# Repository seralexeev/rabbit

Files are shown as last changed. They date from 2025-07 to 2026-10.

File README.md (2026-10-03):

# Rabbit

A small home-built Ackermann rover that maps a flat on its own, drives to things you name ("drive to the fridge") and explains what it did. Everything is in this repo: the robot code, the web HUD, the telemetry store with its AI agent, the hardware design for the next version, and the build log.

Build log (Russian and English): **[rabbit0.dev](https://rabbit0.dev)** · Live HUD: https://live.rabbit0.dev (by personal link)

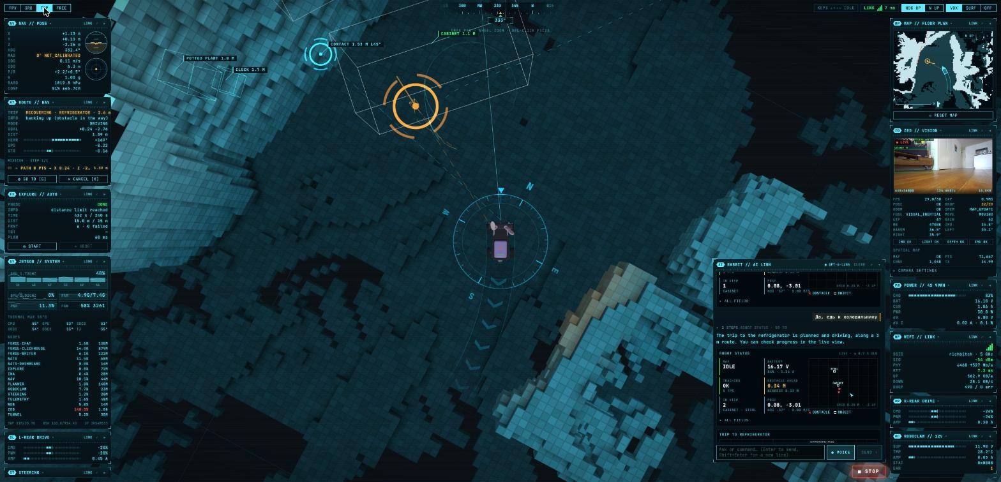
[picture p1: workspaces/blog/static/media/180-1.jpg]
The HUD on a trip to the fridge: voxel map, detected objects, planned path and the AI chat


## What it does

- **Maps and localizes with one stereo camera.** A ZED 2i provides depth, visual-inertial odometry and object detection. nvblox builds a voxel map and a clearance grid on the GPU, and the robot relocalizes in its saved map after a restart. Relocalizing after being carried to another room is the open problem; RTAB-Map is replacing ZED GEN_3 for it.
- **Plans and drives like a car.** A Hybrid A* planner knows the robot's asymmetric turning radius and plans forward and reverse manoeuvres. A path tracker follows the plan on the rear axle, and a collision guard checks the swept footprint against the live obstacle scan.
- **Explores by itself.** It picks views by information gain and finishes a room before leaving it.
- **Takes orders in plain language.** The HUD chat, by text or voice, talks to Forge, an agent that answers from the recorded telemetry ("why did it stop at 03:12?") and can send trips after the operator approves them.
- **Records everything.** Every pose, command, decision with its reason, log line and power sample goes into Parquet files, queried with chDB (embedded ClickHouse).
- **Runs headless.** The HUD is only a viewer: the robot doesn't care whether anyone is watching.

| | |
|---|---|
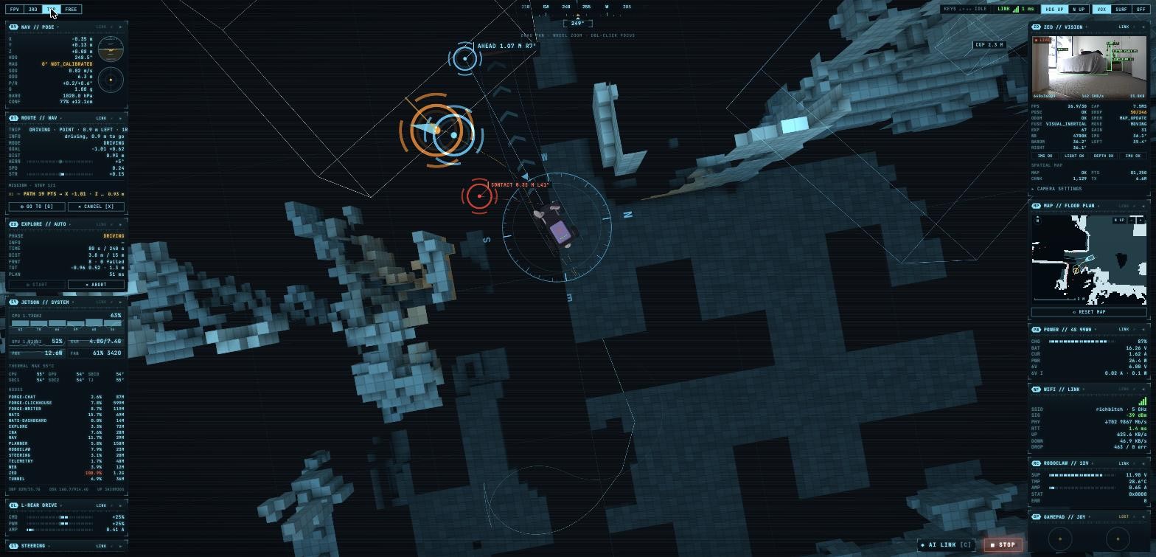
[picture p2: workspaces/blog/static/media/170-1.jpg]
Top view: path, contact warnings and the floor plan
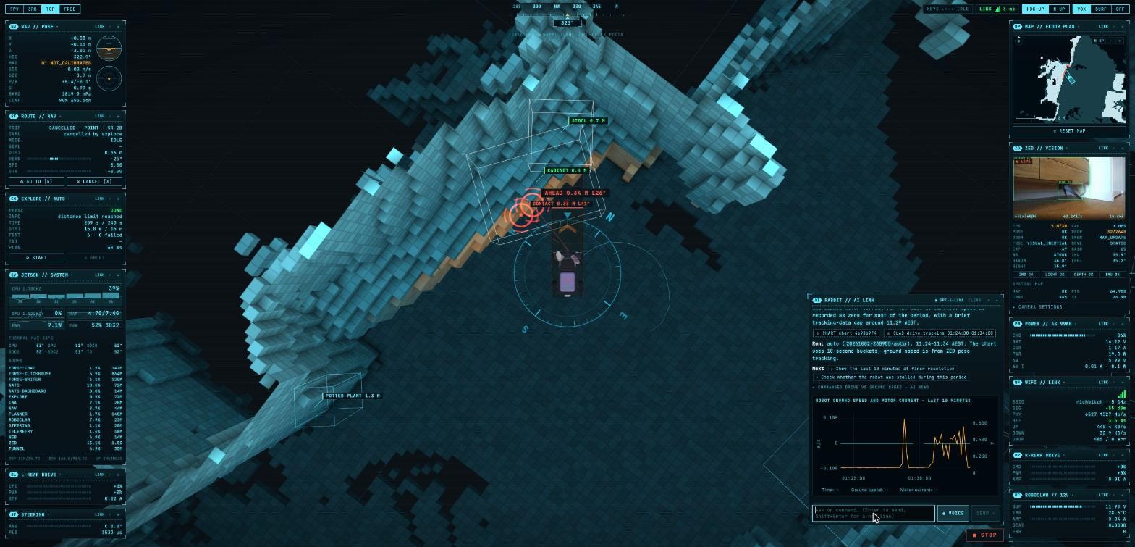
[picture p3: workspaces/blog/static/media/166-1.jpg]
The AI link answering from telemetry with a chart
|  |  |

## Hardware

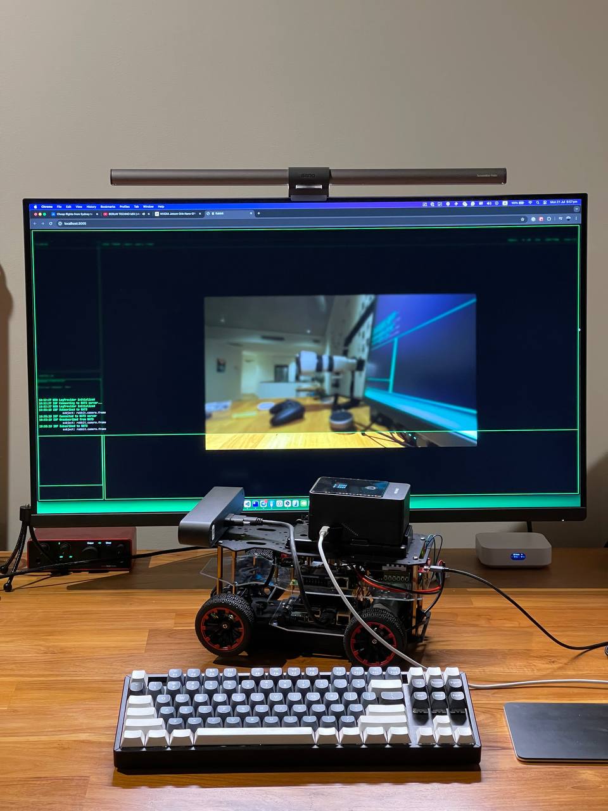
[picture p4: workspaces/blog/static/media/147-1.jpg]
Rabbit on the desk with the early HUD


| Part | What |
|---|---|
| Chassis | "Red Ackerman Racing Car" metal kit; front steering, rear drive. Wheelbase 0.17 m, 75 mm wheels, ~3.5 kg |
| Brain | NVIDIA Jetson Orin Nano Super 8 GB (JetPack 6, MAXN_SUPER, headless) |
| Camera | Stereolabs ZED 2i (depth, VIO, IMU, barometer, magnetometer) |
| Drive | 2 × Pololu 37D 70:1 12 V gearmotors on a RoboClaw 2x30A; electronic differential in software |
| Steering | AGFRC A50BHL brushless servo via a PCA9685 |
| Power | NEEWER PS099E V-mount battery (99 Wh, 4S Li-ion) and Pololu step-down regulators; INA4235 4-channel power monitor |
| Network | Wi-Fi only; NATS over websockets for the HUD; a Cloudflare tunnel for public access |

## Software

Python nodes talk over [NATS](https://nats.io) instead of ROS, one Docker container per node on the Jetson.

```
 ZED 2i ─► rabbit-zed ──pose/odom, obstacle scan, objects, map──► rabbit-nav ──drive──► rabbit-roboclaw ─► motors
              │                                              ▲        │                rabbit-steering ─► servo
              └─► rabbit-loc (RTAB-Map, map←odom)            │        └─ safety trips, recovery
                                   rabbit-planner (Hybrid A*) ┤
                                   rabbit-explore (frontiers) ┘
 rabbit-ina, rabbit-telemetry ─► power, Jetson, Docker, Wi-Fi
 all subjects ─► Forge (Parquet + chDB) ─► slabs, MCP, HUD chat agent
 HUD (React, three.js, uPlot) ◄── NATS websocket, served by rabbit-web (nginx)
```

| Path | What |
|---|---|
| [`workspaces/rabbit`](workspaces/rabbit) | robot nodes (`src/node/`), libraries (`src/lib/`), native extensions (nvblox, RTAB-Map), tests, the simulator |
| [`workspaces/web`](workspaces/web) | the HUD |
| [`workspaces/forge`](workspaces/forge) | Forge: telemetry writer, store, slabs, metric graph, MCP server and chat agent ([README](workspaces/forge/README.md)) |
| [`workspaces/blog`](workspaces/blog) | the build log at rabbit0.dev |
| [`workspaces/bench`](workspaces/bench) | localization benchmark and recording tools |
| [`workspaces/compose.yaml`](workspaces/compose.yaml), [`workspaces/nats`](workspaces/nats), [`workspaces/jetson`](workspaces/jetson) | services, NATS config, Jetson boot tuning |
| [`pcb/rabbit-body`](pcb/rabbit-body), [`cad/brackets`](cad/brackets), [`model`](model) | Rabbit 2.0 body PCB, 3D-printed mounts, chassis model |
| [`docs`](docs) | engineering log, reports, roadmap, open issues, lessons |
| [`scripts`](scripts) | deploy, bring-up, simulator, access links, blog |

## Rabbit 2.0

The next version splits the robot into a **brain** and a **body**:
- the Jetson keeps only GPU work: perception, localization and planning;
- a Raspberry Pi 4 becomes the body. It runs the motors, the steering, the power, an independent safety loop, a 360° lidar, ToF sensors and bumpers, a rear camera, Forge and the HUD.

The body electronics move from an acrylic deck full of modules onto one PCB shaped like the chassis deck. The board is generated from Python with KiCad and Freerouting.

| | |
|---|---|
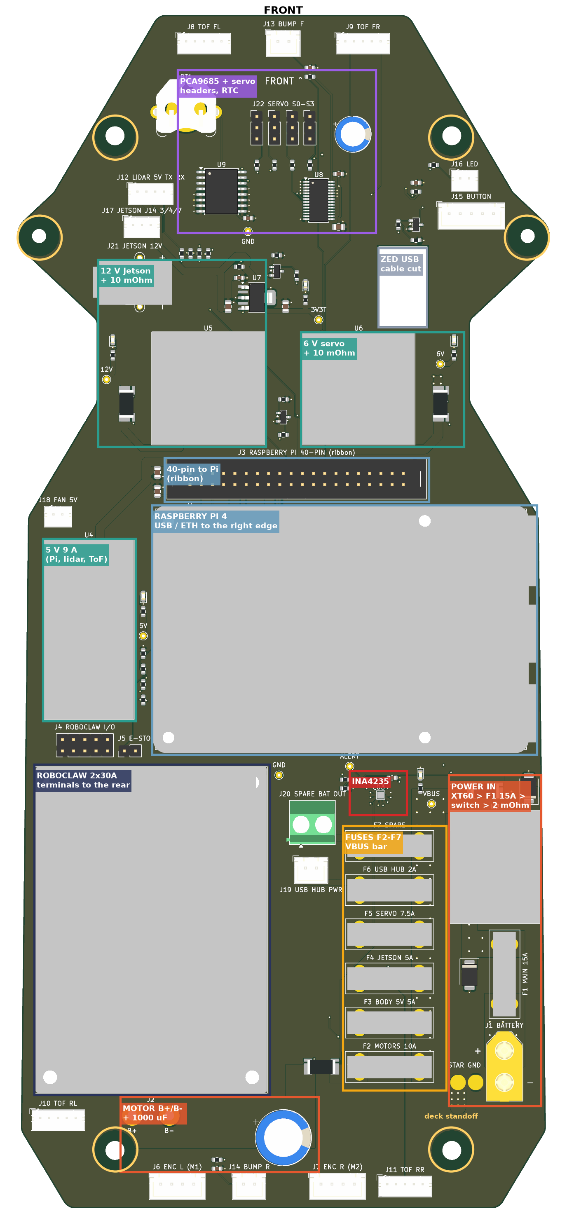
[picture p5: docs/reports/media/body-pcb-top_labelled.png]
Body PCB, top view with the main blocks labelled
|  | Wiring overview: every device and link |
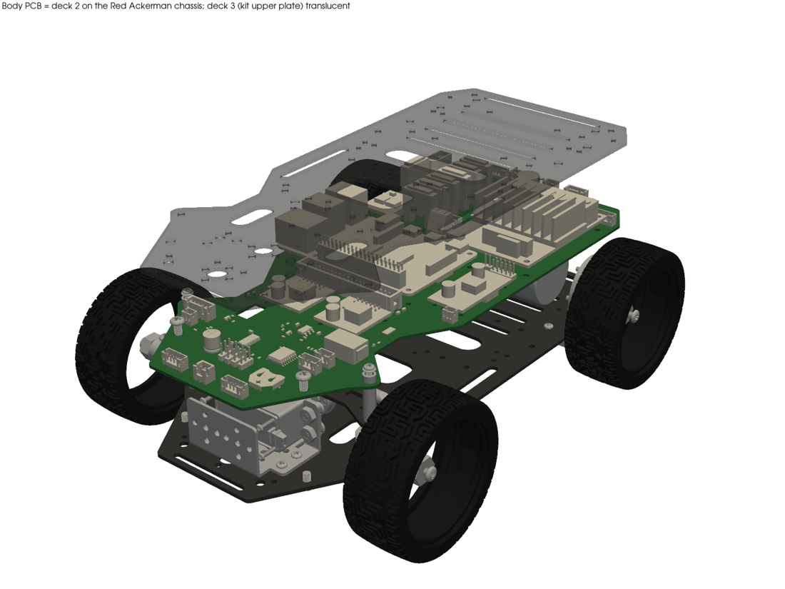
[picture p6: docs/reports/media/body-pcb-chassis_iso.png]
The PCB as the middle deck on the chassis
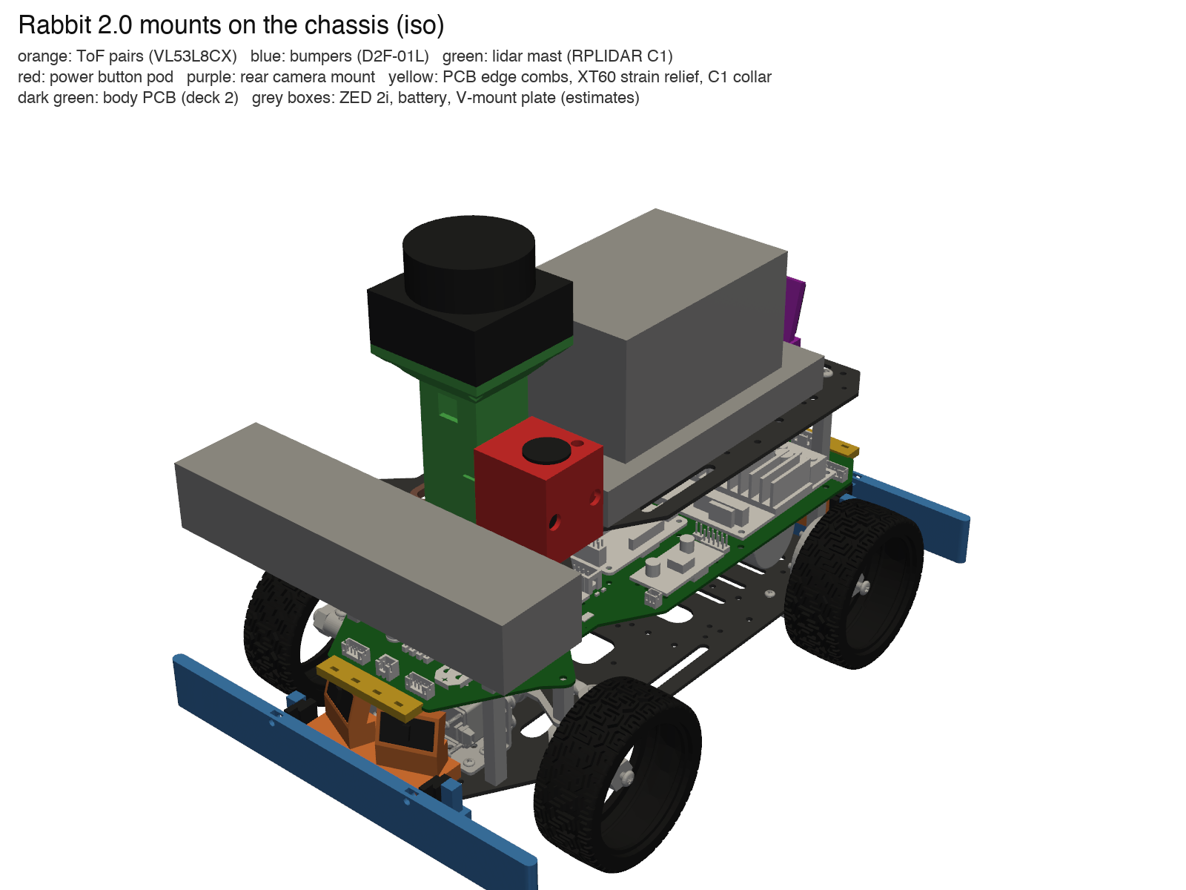
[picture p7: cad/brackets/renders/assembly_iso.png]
3D-printed mounts: ToF pairs, bumpers, lidar mast
|  |  |

Design: [architecture](docs/reports/2026-10-03-architecture-2.0.md) · [wiring](docs/reports/2026-10-03-architecture-2.0-wiring.md) · [BOM](docs/reports/2026-10-03-architecture-2.0-bom.md) · [body PCB](docs/reports/2026-10-03-body-pcb.md) · [mounts](docs/reports/2026-10-03-mounts.md) · [power](docs/reports/media/power-2.0.svg)

## Working on it

The project is developed mostly by coding agents. [`AGENTS.md`](AGENTS.md) holds the rules, and the skills in [`.claude/skills`](.claude/skills) hold the procedures:
- `rabbit-robot`: operating and deploying the robot;
- `rabbit-dev`: robot code and the HUD;
- `forge-dev`: Forge;
- `rabbit-blog`: the blog.

```sh
# robot tests
cd workspaces/rabbit && uv run --no-project --python 3.10 --with pytest --with numpy --with pydantic --with numba --with nats-py python -m pytest tests -q

# full-stack simulator on the Mac: local NATS + rabbit-sim + the real nav, planner and explore
scripts/sim.sh

# HUD dev server at https://localhost:3005
cd workspaces/web && node ../../.yarn/releases/yarn-4.9.3.cjs dev

# deploy named services to the robot
scripts/deploy.sh rabbit-nav rabbit-web

# after the robot was off: checks, deploy, tests, step by step
uv run scripts/bringup.py check
```

## Work log and blog

Every piece of significant work leaves two traces, written as part of the work:

1. **Engineering log** in [`docs/`](docs/README.md), in English and factual:
   - `docs/log/YYYY-MM-DD-<topic>.md`: what was tried and dropped, numbers, root causes;
   - [`docs/roadmap.md`](docs/roadmap.md): what's next;
   - [`docs/open-issues.md`](docs/open-issues.md): open questions and unresolved problems;
   - [`docs/lessons.md`](docs/lessons.md): rules learned the hard way.
2. **Blog post** at [rabbit0.dev](https://rabbit0.dev), in the author's voice:
   - source in [`workspaces/blog`](workspaces/blog): `README.ru.md` holds the Russian posts, `README.md` the English ones, `static/media/` the media;
   - `scripts/blog.sh build` renders the pages;
   - a push to `main` that touches `workspaces/blog` deploys it to GitHub Pages ([`.github/workflows/blog.yml`](.github/workflows/blog.yml)).

## Access links

The public HUD at https://live.rabbit0.dev opens only through a personal link; the LAN address (https://jetson.rabbit) stays open. Ask the agent "give me a link" (optionally "for Alice") or "remove Alice's link", or run it yourself:

```sh
scripts/links.sh              # list: name, date, link
scripts/links.sh add alice    # create a link, prints https://live.rabbit0.dev/k/<token>
scripts/links.sh rm alice     # revoke it: the open HUD is cut off within ~5 s
```

The registry lives only on the robot, in `/root/rabbit/workspaces/links/links.map`. Details are in the `rabbit-robot` skill.

Old hardware and setup scratch notes: [`docs/notes.md`](docs/notes.md).

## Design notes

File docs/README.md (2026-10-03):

# Engineering log

Notes for people and agents who pick up this project later: what the system looks like now, how it got there, what was tried and dropped, the measurements behind decisions and the incidents with their root causes. The how-to material (deploying, operating, developing) lives in `AGENTS.md`, `.claude/skills/*` and `workspaces/forge/README.md`; this folder is the history and the reasoning.

Open questions, unresolved problems and on-robot checks: [open-issues.md](open-issues.md). What to do next: [roadmap.md](roadmap.md).

Conventions: dates in file names and timestamps are UTC unless marked otherwise; the robot and its owner are in Sydney (AEST, UTC+10, AEDT from 4 October 2026). Commit hashes refer to this repository. Everything after commit `b36435d` (2026-10-02 00:49 UTC) was uncommitted when these notes were written (2026-10-03); those entries name files instead of commits. Reports referred to as `~/projects/rabbit/data/offline/...` are kept outside the repo because they contain maps and data of the flat.

What's next: [roadmap.md](roadmap.md).

## Index

| Entry | Topic |
|---|---|
| [2025-05-18 hardware and stack history](log/2025-05-18-hardware-and-stack-history.md) | hardware, the move from Raspberry Pi to Jetson, ROS 2 → NATS, state after five months off |
| [2026-10-01 revival and telemetry](log/2026-10-01-revival-and-telemetry.md) | node rewrite, RoboClaw/INA/IMU telemetry, `jetson_clocks`, TLS and Chrome |
| [2026-10-01 ZED spatial mapping](log/2026-10-01-zed-spatial-mapping.md) | SDK 5.5, room map, memory, quality tuning, mesh filter, chunk format (superseded) |
| [2026-10-01 driving, nav and safety](log/2026-10-01-driving-nav-and-safety.md) | nav node, missions, swept-arc guard, wall crash, calibration, rear-axle tracking |
| [2026-10-01 exploration and Hybrid A*](log/2026-10-01-exploration-and-hybrid-astar.md) | frontier exploration and the planner kernels |
| [2026-10-01 Forge](log/2026-10-01-forge.md) | ClickHouse writer, slabs, MCP, chat agent, anomalies, moving onto the robot |
| [2026-10-01 HUD](log/2026-10-01-hud.md) | 3D HUD, chat panel, minimap, voxel map, objects |
| [2026-10-01 lag and Wi-Fi](log/2026-10-01-lag-and-wifi.md) | the lag hunt, Wi-Fi drops, TX power |
| [2026-10-01 public access](log/2026-10-01-public-access.md) | Cloudflare tunnel, access links, HTTP/2 |
| [2026-10-01 map resets](log/2026-10-01-map-resets.md) | every map reset or loss and its cause |
| [2026-10-01 deploy and agent workflow](log/2026-10-01-deploy-and-agent-workflow.md) | deploy script, parallel agent sessions |
| [2026-10-02 Jetson performance](log/2026-10-02-jetson-performance.md) | clocks, IRQs, headless, the clock-floor incident, OC3, JetPack assessment |
| [2026-10-02 ZED optimisation](log/2026-10-02-zed-optimisation.md) | CPU, GIL, frame rates, depth, GEN_3 keyframe leak, map modes |
| [2026-10-02 nvblox](log/2026-10-02-nvblox.md) | nvblox extension, clearance grid, reflections, debris |
| [2026-10-02 floor estimation](log/2026-10-02-floor-estimation.md) | floor origin, per-frame floor plane, robot on a table |
| [2026-10-02 route planner](log/2026-10-02-route-planner.md) | `rabbit-planner`: trips to points, places and objects; replay |
| [2026-10-02 object detector](log/2026-10-02-object-detector.md) | YOLOE in the ZED SDK, filtering, objects in Forge |
| [2026-10-02 voice agent](log/2026-10-02-voice-agent.md) | Realtime voice, spoken approvals, robot prompt |
| [2026-10-02 relocalization](log/2026-10-02-relocalization.md) | millimetre poses, false relocalization, give-up rules |
| [2026-10-02 odom/map split](log/2026-10-02-odom-map-split.md) | nav on continuous odometry |
| [2026-10-02 operator heartbeat removal](log/2026-10-02-operator-heartbeat-removal.md) | the HUD is a viewer |
| [2026-10-02 NATS/Docker latency](log/2026-10-02-nats-docker-latency.md) | latency audit and NATS settings |
| [2026-10-02 SLAM survey and benchmark](log/2026-10-02-slam-survey-and-benchmark.md) | cuVSLAM / RTAB-Map vs ZED GEN_3 (in progress) |
| [2026-10-03 motor slew limit](log/2026-10-03-motor-slew-limit.md) | smoothing bursty joystick commands |
| [2026-10-03 Forge on Parquet and chDB](log/2026-10-03-forge-parquet-chdb.md) | ClickHouse server replaced by Parquet files and embedded chDB: design, parity, memory |
| [2026-10-03 Jetson diet and Python 3.12](log/2026-10-03-jetson-diet.md) | trimming host services, journald, logrotate, image pruning; Python 3.12 patch |
| [2026-10-03 field session](log/2026-10-03-field-session.md) | boot after a move, recordings, nav safety trips, far-floor phantom obstacles |
| [2026-10-03 power rails](log/2026-10-03-power-rails.md) | battery, motor, servo and Jetson currents from telemetry; the motor buck at its limit, the battery shunt near its range |
| [2026-10-03 Rabbit 2.0 made buildable](log/2026-10-03-architecture-2.0-detail.md) | Pi 4 body: BOM, pinout and buses, fail-safe E-stop, NATS hub + leaf, INA4235 channels and shunts, wiring diagrams |
| [2026-10-03 nav replay](log/2026-10-03-nav-replay.md) | offline replay of the day's trips: recovery along the trail, turnaround loops, `stuck`, IMU thresholds |
| [2026-10-03 full-stack simulator](log/2026-10-03-full-stack-sim.md) | `rabbit-sim` + local NATS + the real nav/planner/explore on the Mac, end-to-end tests |
| [2026-10-03 observability](log/2026-10-03-observability.md) | structured events with reasons and ids, node metrics, start snapshots, `events` / `node_starts` / `node_metrics` / `nats_server` in Forge |
| [2026-10-03 phase 0 tools](log/2026-10-03-phase-0-tools.md) | INA per-channel shunts and `clipped`, duty cap 12 V / V_supply, RoboClaw config tool (3 A, NVM), encoder check |
| [2026-10-03 printed mounts](log/2026-10-03-printed-mounts.md) | Rabbit 2.0 brackets in `cad/brackets/`: ToF pairs, compliant bumpers with D2F switches, lidar mast (scan plane 230 mm), button pod, rear camera mount, body-PCB clips and grommets; fit checks against the 3-deck stack with the PCB STEP; the USB hub has no place yet |
| [2026-10-03 body PCB](log/2026-10-03-body-pcb.md) | deck-2 board for Rabbit 2.0 generated by code (KiCad 10 + Freerouting): Pi, RoboClaw, regulators, fuses, INA4235, PCA9685; stack heights, current paths, DRC clean, JLCPCB outputs |
| [2026-10-03 body PCB review](log/2026-10-03-body-pcb-review.md) | independent pre-order review of rev A: pin-by-pin checks pass; fixed input TVS, ToF and 5 V rail resistance, motor star, stale net classes, ZED cut-out, INA4235 paste, BOM; PCA9685/INA4235 stock blocks JLC assembly; factory-assembly options and rev B lessons |
| [2026-10-03 BLDC drive study](log/2026-10-03-bldc-drive.md) | why the 37D 70:1 is slow and loud, torque/speed needs per wheel, the motor mount measured in the chassis model, BLDC/brushed/gimbal options, DRV8316 + STM32G4 on the body PCB, regen with a V-mount BMS; report `reports/2026-10-03-bldc-drive.md` |
| [2026-10-03 BLDC drive mount](log/2026-10-03-bldc-drive-mount.md) | final BLDC choice (maxon ECX FLAT 22 L + GPX 22 LN 16:1 + ENX 22 MILE; Faulhaber 3216 fallback), new 6061 bracket with its own wheel bearings and an Oldham coupling inside a hollow stub axle, printed test-fit variant, fit check in the widened chassis, wiring to the rev B connectors; `cad/drive/` |
| [2026-10-03 body software](log/2026-10-03-body-software.md) | Rabbit 2.0 body written offline: `rabbit-lidar` (RPLIDAR C1 protocol, timestamps, de-skew), `rabbit-tof` (VL53L8CX ×4, floor rejection), `rabbit-safety` (50 Hz arbiter, caps by clearance and input freshness, E-stop line self-test), `rabbit-power` (shutdown state machine), fake GPIO/serial/ToF backend, lidar/ToF/bumpers in the simulator, nav and planner on the lidar scan, Forge tables, Pi compose and deploy; Raspberry Pi kernels keep GPIO outputs after a crash |
| [2026-10-03 body PCB rev B](log/2026-10-03-body-pcb-rev-b.md) | deck-2 board rev B: STM32G474 + 2× DRV8316 BLDC drive with hardware E-stop and brake chopper, LM74800 soft-latch switch, LM61495 bucks, TPS16630 Jetson eFuse, 4× INA226, SMD fuses, GND_MOT island; everything JLC-stocked and JLC-assembled; Freerouting fed filled pours |

[lessons.md](lessons.md) collects the hard-won rules in one list.

## Current state of the system (2026-10-03)

### Hardware

Jetson Orin Nano Super 8 GB (MAXN_SUPER, clocks pinned, headless), ZED 2i on USB, RoboClaw 2x30A on the UART, PCA9685 steering servo, INA4235 power monitor, 99 Wh 4S Li-ion pack, Wi-Fi only. Wheel encoders do not count; speed comes from the camera pose. Details in the hardware entry.

### Services (`workspaces/compose.yaml`)

| Service | Role |
|---|---|
| `nats`, `nats-init`, `nats-dashboard` | message bus; KV bucket `rabbit`, JetStream `LOGS` (7 days) |
| `rabbit-zed` | the only camera process: GEN_3 tracking and relocalization, depth (NEURAL_LIGHT, every 2nd frame), nvblox mapping (C++/CUDA extension), floor estimation, obstacle scan, YOLOE object detection, preview, SVO recording, health |
| `rabbit-nav` | missions (`move`, `turn`, `goto`, `path`), path tracking on the rear axle in the odometry frame (curvature feedforward + feedback), swept-footprint collision guard with blind-zone memory, stall and bump trips |
| `rabbit-planner` | Hybrid A* trips to points, saved places and objects; replanning and recovery |
| `rabbit-explore` | exploration by expected information gain per metre, through planner trips |
| `rabbit-roboclaw`, `rabbit-steering` | motors (electronic differential, slew limiting, kill switch) and the servo |
| `rabbit-ina`, `rabbit-telemetry` | power at 50 Hz; Jetson, containers and Wi-Fi at 1 Hz |
| `forge` | NATS → Parquet writer, compaction, chDB queries, chat/voice agent API, in one process |
| `rabbit-web` | nginx: the built HUD, `/api` → chat, `/nats` → NATS websocket, access-link gate |
| `tunnel` | Cloudflare tunnel (HTTP/2) to https://live.rabbit0.dev |

All `rabbit-*` nodes share one image with the code bind-mounted; a code change needs a container recreate, not a rebuild.

### Main NATS contracts

- Sensors: `rabbit.zed.pose` (map pose plus an `odom` sub-object; floor at y = 0, camera at y ≈ 0.137), `rabbit.zed.imu`, `rabbit.zed.obstacle` (48-bin scan over ±60°, obstacles 4–45 cm above a per-frame floor plane), `rabbit.zed.objects`, `rabbit.health.zed` (fps, `spatial_memory_status`, `relocalizing`, `map_mode`, `map_id`, nvblox timings), `rabbit.roboclaw`, `rabbit.ina`, `rabbit.steering`, `rabbit.telemetry`.
- Commands: `rabbit.cmd.joy` (owns the motors for 1 s), `rabbit.cmd.drive`, `rabbit.nav.mission`, `rabbit.nav.cancel`, `rabbit.nav.explore`, `rabbit.planner.goal` (request/reply, `preview`), `rabbit.planner.places*`, `rabbit.zed.wake`, `rabbit.zed.record`.
- Map: `rabbit.map.chunks` / `rabbit.map.snapshot` (mesh blocks, `<IIIfff` header, int16 mm vertices relative to a per-chunk origin), `rabbit.map.grid` / `.snapshot` (int16 mm clearance, 5 cm cells), `rabbit.map.save`, `rabbit.map.reset`, `rabbit.map.extend` (request/reply).
- State: `rabbit.nav.state` (10 Hz), `rabbit.planner.state`, `rabbit.explore.state`, logs on `rabbit.log.<node>`.
- `rabbit.operator.heartbeat` only raises the idle camera rate; nothing depends on the HUD being open.
- Rabbit 2.0 body (written and simulated, not deployed): `rabbit.lidar.scan` (binary rotation, Pi clock), `rabbit.tof` (per-sensor frames with obstacle points), `rabbit.safety.drive` / `.state` / `.estop` / `.reset`, `rabbit.power.state` / `.request` / `.jetson`, `rabbit.health.lidar` / `.tof`; contracts in [log/2026-10-03-body-software.md](log/2026-10-03-body-software.md). nav and the planner already take `rabbit.lidar.scan` when it appears.

### Map and localization pipeline

ZED depth + GEN_3 pose → plausibility filter (millimetre poses, jump gate) → floor estimator → nvblox TSDF/ESDF on the GPU (5 cm voxels, rays clipped at the floor, integration up to 5 m) → mesh blocks for the HUD and the 2D clearance grid for the planner. The SDK area memory (`room.area`) provides relocalization after restarts; `map_mode` keeps it in localization by default and extends it only for a new map or exploration (GEN_3 keeps adding keyframes otherwise). Saved state in `data/map/`: `room.area`, `room.nvblx`, `room.id`, `room.ply`, `archive/` (last 5). Relocalization counts after 10 s of a localized status; it gives up after 3 m of travel or 45 s and starts a new map.

### Planner

Hybrid A* (numba) on the clearance grid with asymmetric curvature tables, costs that keep to the middle of gaps, reverse only into mapped space, Dijkstra heuristic; plans in 5–80 ms typically on the Jetson. Trips replan on new obstacles, pose jumps and blocks, back up along their own trail, and hold before long detours. Object goals come from Forge's object memory.

### Forge

Parquet files on the robot (one file per table and hour every 10 s, merged hourly), queried in-process with chDB; one container of about 300 MB instead of ClickHouse, writer and chat (600–850 MB). See [2026-10-03 Forge on Parquet and chDB](log/2026-10-03-forge-parquet-chdb.md). Slabs, a static SQL gate plus EXPLAIN, a metric graph with `investigate`, Chronos-2 anomaly detection, MCP tools, a chat agent (OpenAI via the Vercel AI SDK) and a Realtime voice agent, both with approval cards for motion. Every node records its decisions as structured events with a reason, ids and the measured values (`events`), its start snapshot (`node_starts`) and its process health (`node_metrics`); conventions in [reports/2026-10-03-observability.md](reports/2026-10-03-observability.md).

### HUD

React/three.js at https://jetson.rabbit (LAN) and https://live.rabbit0.dev (access link required): 3D view with a voxel or surface map, minimap, objects, panels with uPlot charts, gamepad/keyboard driving, AI LINK chat with voice.

### In progress / open

- **Forge storage cutover to Parquet + chDB is staged but not switched** (runbook: `reports/2026-10-03-forge-cutover-runbook.md`). Until it's done, don't run `scripts/deploy.sh` without arguments or with `forge-*`: the working tree's Forge code no longer runs in the old alpine containers. Deploying `rabbit-*` services is safe. `forge-shadow` (the new writer) starts on boot.
- Localization replacement: odometry from cuVSLAM or ZED VIO plus RTAB-Map as the global localizer, being benchmarked on recorded SVOs; ground-truth floor markers and wake-up sessions still to record.
- Commit the work since `b36435d` (planner node, nvblox extension, detector, voice, access links, relocalization fixes, odom split).
- Make `rabbit-zed` survive an nvblox CUDA out-of-memory.
- Wi-Fi in the far part of the flat (router RSSI settings, antennas or another card).
- Actual clocks and OC counters in Forge; Python 3.12; Docker image cleanup; RTC battery and persistent journal.
- `pose` Euler angles in Forge: rows recorded before the writer fix of 2026-10-03 hold yaw in `pitch_deg`, roll in `yaw_deg` and pitch in `roll_deg` (ZED `euler_deg` is rotation about x, y, z in the Y-up frame: pitch, yaw, roll); newer rows are correct.
- Encoders read 0; the magnetometer is not calibrated.
- Rabbit 2.0 body software (`safety`, `power`, `lidar`, `tof` nodes, `workspaces/body/`) waits for the parts; bring-up checks are open-issues V7–V12.
- Body PCB rev B (`pcb/rabbit-body/`, BLDC drive on board) is designed, not ordered; it needs MCU firmware and `ina.py` for INA226 before it can replace the RoboClaw setup (`reports/2026-10-03-body-pcb-rev-b.md` §12).

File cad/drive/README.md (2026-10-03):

# Rabbit rear drive: BLDC motors, brackets and wheel coupling

The owner chose BLDC drive motors and accepted new brackets (Q39, 2026-10-03). This folder holds the bracket, the motor flange, the wheel coupling and the fit check against the widened chassis. Study and choice: `docs/reports/2026-10-03-bldc-drive.md` §13 (Russian), log `docs/log/2026-10-03-bldc-drive-mount.md`.

```bash
cd cad/drive
uv run --project ../../model python bracket.py     # bracket.step (CNC), bracket_print.3mf/.stl, motor_flange_<maker>.step/_print.3mf
uv run --project ../../model python coupling.py    # stub_axle, inner_spacer, oldham_disc, oldham_hub_<maker> (.step)
uv run --project ../../model python drawing.py     # drawings/*.pdf + .png with fits and tolerances
uv run --project ../../model python assembly.py    # fit checks (renders/fit_report.json), renders/, drive-assembly.step (~5 min)
```

`assembly.py` reuses `cad/brackets/assembly.py`: the 3-deck stack, the body PCB STEP as deck 2, the printed mounts. It removes the kit's rear drive (brackets, 37D motors, hubs, screws) and moves the rear wheels out by 10.7 mm per side.

## Motor

**maxon ECX FLAT 22 L 18 V (sealed, "HTQ") + GPX 22 LN 16:1 + ENX 22 MILE 1024**, configuration code **B845D2FFA4A0** in the maxon configurator (designations `ECXFL22L KL A HTQ 18V`, `GPX22 LN 16:1`, `ENX 22 MILE 1024IMP`). €429.78 per drive in the maxon shop (1–4 pcs, excl. VAT); maxon Australia (Mt Kuring-Gai NSW, +61 2 9457 7477, sales.au@maxongroup.com) quotes in CHF, about CHF 409 per drive (≈ A$770 ex GST).

| At 14 V, per wheel | maxon (chosen) | Faulhaber 3216W012BXTH + 22GPT 11:1 + IEF3-4096 (alternative) |
|---|---|---|
| No-load / at 0.2 N·m | 2.35 / 2.08 m/s (2.82 m/s free at 16.8 V; firmware cap 10,000 motor rpm = 2.52 m/s) | 2.62 / 2.41 m/s |
| Current at 0.2 / 0.6 N·m | 1.22 / 3.46 A | 1.37 / 3.86 A |
| Gearhead continuous / intermittent | 0.55 / 0.70 N·m (plastic planets, −5 dB(A) vs standard) | 0.8 / 1.1 N·m (stainless) |
| Output shaft | Ø4 × 14.85, flat 3.5 over 9.3 | Ø6 × 16.3, flat 5.4 over 10 |
| Encoder | 1024 lines (4,096 counts/motor rev, 63,800 per wheel rev), A/B + inverted, no index | 4096 lines (16,384 counts/motor rev), A/B/I push-pull |
| Length behind the flange / Ø | 46.3 mm / Ø22 (Hall board sticks out to ~R17, mounted up) | 49.2 mm / Ø22 gearhead, **Ø32 motor**, cable block to R21 |
| Fit here | clear: 4.3 mm above deck 1, 22.9 mm between the two motors | **motor body 0.67 mm into deck 1** (32 mm³ per side): needs a ~14 × 24 mm window filed into deck 1 each side (Q20) |

The bracket, stub axle and Oldham disc are the same for both; only the motor flange and the Oldham hub (bore Ø4 vs Ø6) change.

## How it works

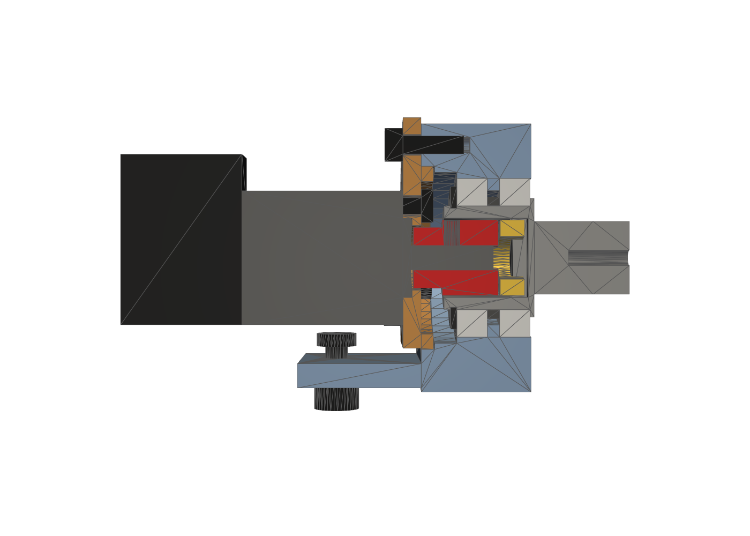
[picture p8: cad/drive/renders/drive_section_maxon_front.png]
drive section


- **The bracket carries the wheel, not the motor.** An L in 6061: a 4 mm foot under deck 1 on the kit's two M4 holes (slots allow ±1 mm fore-aft), and a housing outboard of the plate edge with two SKF 61803-2RS1 (17 × 26 × 5) on either side of a 2 mm shoulder. The hollow stainless stub axle runs in them; its outboard end is the kit's 12 mm hex with the M3 axial thread, so the wheel goes on exactly as before.
- **Torque only through the gearhead shaft.** The gearhead shaft sits inside the hollow stub. Hub A (on the shaft, set screw on the flat) drives a PEEK Oldham disc, which drives the cross slot at the bottom of the stub bore. The disc floats ±0.3 mm, so the two sets of bearings never fight. Wheel loads (12 N static, ~60 N on a 5 g bump, plus cornering) go stub → bearings → bracket → deck 1.
- **Motor flange.** The gearhead bolts to a 3 mm plate that spigots (Ø30 g6/H7) into the bracket and is held by 3 × M3. The motor comes out with three screws from the motor side; the bearings and the wheel stay put.
- **Same axle as today**: wheel axis 44.46 mm above deck 1's model origin (15.3 mm above the deck top), same y, wheel in the same place relative to the bracket's inner face.

Bearing loads (`fit_report.json` → `loads`): wheel centre 18.3 mm outboard of the outer bearing, span 7 mm. Static: 44 N on the outer bearing; 0.7 g cornering: 89 N; 5 g bump + cornering: 265 N, static safety s0 = 3.9 on C0 = 1.04 kN. The gearhead shaft sees no wheel load. For comparison, the GPX 22 LN is rated 100 N at 10 mm from its flange and the wheel centre would be ~37 mm away: hanging the wheel on the gearhead was marginal, hence the bearings.

## Fit check (`assembly.py`, chassis widened to 142 mm between the bracket faces)

| Check | maxon | Faulhaber |
|---|---|---|
| Interference with the chassis (deck 1, standoffs, wheels), the body PCB STEP (266 solids), the printed mounts and between drive parts | none | motor body into deck 1, 32 mm³ per side |
| Gap between the two motors' rear ends | 22.9 mm | 17.1 mm |
| Motor to deck 1 top | 4.3 mm | −0.67 mm |
| Bracket top / motor to the body PCB (incl. THT pins) | 7.8 / 12.7 mm | 7.8 / 8.7 mm |
| Motor flange to deck 1 | 0.5 mm (flat cut) | 0.5 mm |
| Bracket to the wheel's inner face | 1.0 mm | 1.0 mm |
| Foot slots over the deck 1 M4 holes (4 screws) | all 4 match | all 4 match |
| Lowest point (M4 nuts) above the floor | 11.1 mm (inside the tyre's silhouette, so a step meets the tyre first) | same |

Renders (`renders/`):
- whole robot: `assembly_<maker>_{iso,top,rear}.png`;
- rear axle, deck 3 hidden: `rear_<maker>_{iso_rear,top,rear}.png`;
- section through the axle: `section_<maker>_front.png`;
- one side alone: `drive_<maker>_{iso,iso_rear}.png`, `drive_section_<maker>_front.png`.

## Make

### CNC (primary): JLCCNC or PCBWay CNC

Upload the STEP and the PDF drawing of each part; ask for the tolerances on the drawing (they need the "precision" option, ±0.01).

| Part | File | Material, finish | Qty | Critical |
|---|---|---|---|---|
| Bracket | `bracket.step` (robot left; mirror for the right, or order "1 + 1 mirrored") | 6061-T6, bead blast + anodise | 2 | bearing seats Ø26 J7 coaxial Ø0.02 to the spigot seat Ø30 H7; shoulder 2.00 +0.02/0 (`drawings/bracket.pdf`) |
| Motor flange | `motor_flange_maxon.step` | 6061-T6 | 2 | spigot Ø30 g6 coaxial to the pilot pocket Ø13 H7 (`drawings/motor_flange_maxon.pdf`) |
| Stub axle | `stub_axle.step` | stainless 303 | 2 | Ø17 k5, groove DIN 471-17, slot 3.5 F7, hex 12 A/F, M3 × 10 (`drawings/coupling_maxon.pdf`) |
| Oldham hub A | `oldham_hub_maxon.step` | stainless 303 | 2 | bore Ø4 H7, slot 3.5 F7, M3 set-screw hole |
| Oldham disc | `oldham_disc.step` | PEEK (natural) | 2 + 2 spare | tongues 3.48 h7 |
| Inner-ring spacer | `inner_spacer.step` | stainless | 2 | 2.00 0/−0.02 |

The bracket is drawn and exported as the robot-left part. The right-hand part is its mirror image. It is symmetric about its own y = 0 plane except for the foot slots (26.90 mm pitch, off-centre by 0.08 mm), so in practice the same part fits both sides.

### Print (test fit): Bambu Lab P2S

| Part | File | Material | Orientation | Settings |
|---|---|---|---|---|
| Bracket | `bracket_print.3mf` | PA-CF (or PETG for a first look) | outboard face down, as exported: bores vertical | 5 walls, 40% gyroid, 0.2 mm; ~2 h, ~30 g. The 2 mm bearing shoulder is the only ledge (prints without supports); clean it with a 22 mm drill or file |
| Motor flange | `motor_flange_maxon_print.3mf` | PA-CF / PETG | flat, as exported | 100% infill |

Print bores are +0.10 mm. Press the bearings in by hand with a drop of CA. M3 heat-set inserts (Ø4.0 × 6) replace the tapped holes. Use a metal stub axle even on the printed bracket.

## Assemble

1. Bearings into the bracket: the outer one from the wheel side against the shoulder, the inner one from the motor side; Loctite 641 on the outer rings.
2. Stub axle in from the wheel side, the 2 mm inner-ring spacer between the bearings, DIN 471-17 circlip from the motor side.
3. Bracket to deck 1: M4 × 10 button heads from the top through the deck's holes, nyloc nuts under the foot. Slide it fore-aft in the slots so the wheel runs straight, then tighten.
4. Wheel on the hex, kit M3 × 8 + washer, as before.
5. Motor: gearhead to the motor flange (3 × M3 × 6 DIN 7984, Loctite 243). Then hub A on the shaft with its face 15.6 mm from the gearhead face (a printed gauge or calipers), M3 × 3 cup-point on the flat, Loctite 243. Put the disc in the stub bore and turn the wheel until the slot lines up. Push the motor in so the spigot seats, then fit 3 × M3 × 10 ISO 4762 from the motor side.
6. Hall board up. Cables go out at the motors' rear ends, at the centreline, back to J41–J46 on the PCB's rear edge (~45 mm away). Tie them to deck 1's slot at y 99.

## BOM (two drives)

| Item | Qty | Order | Note |
|---|---|---|---|
| maxon ECX FLAT 22 L 18 V HTQ + GPX 22 LN 16:1 + ENX 22 MILE 1024 | 2 (+1 spare) | config B845D2FFA4A0, maxon AU | €429.78 each (shop), ≈ A$770 ex GST |
| SKF 61803-2RS1 (17 × 26 × 5) | 4 (+2) | SKF via CBC / BSC / Bearing Wholesalers | ~A$15–25 each [estimate] |
| Circlip DIN 471 17 × 1.0, stainless | 2 (+4) | | |
| Socket set screw M3 × 3 cup point ISO 4029, 45H | 2 (+2) | | Loctite 243 |
| ISO 4762 M3 × 10 A2 | 6 | | flange → bracket |
| DIN 7984 M3 × 6 A2 (low head) | 6 | | gearhead → flange (maxon) |
| ISO 7380 M4 × 10 A2 + DIN 985 M4 nyloc | 4 + 4 | | bracket → deck 1 |
| M3 × 8 + washer | kit | | wheel screw, reused |
| CNC parts (table above) | 2 sets | JLCCNC / PCBWay | ~US$200–260 for two sets [estimate] |
| Faulhaber instead | 2 | ERNTEC Pty Ltd (Scoresby VIC, +61 3 9756 4000), the Faulhaber partner for AU/NZ | price on request; then `motor_flange_faulhaber`, `oldham_hub_faulhaber`, 6 × DIN 7984 M2 × 5 and a window in deck 1 |

## Wiring to the body PCB (rev B connectors, no board change)

| PCB | maxon lead | Adapter |
|---|---|---|
| J41/J42 phases, Molex KK 396 3-pin: 1 A, 2 B, 3 C | Molex 39-01-2040 (Mini-Fit Jr 4): 1–3 phases, 4 n.c. | pigtail Mini-Fit Jr 4 → KK 396 3 (09-50-8031), AWG 22 |
| J43/J44 Halls, JST PH 5: 1 5V_HALL, 2 GND, 3 HA, 4 HB, 5 HC | Molex 43025-0600 (Micro-Fit 6): 1 H1, 2 H2, 3 H3, 4 GND, 5 V_Hall (3.5–24 V), 6 n.c. | 5→1, 4→2, 1→3, 2→4, 3→5 |
| J45/J46 encoder, JST GH 7: 1 5V, 2 3V3, 3 GND, 4 A, 5 B, 6 Z, 7 GND | ENX 22 MILE, 10-pin 2.54 IDC: 2 Vcc, 3 GND, 5 /A, 6 A, 7 /B, 8 B | 2→1, 3→3, 6→4, 8→5; /A, /B and GH 2, 6 not connected |

Faulhaber: Micro-Fit 43025-0800 (1 phase C, 2 B, 3 A, 4 GND, 5 +5 V, 6 Hall C, 7 Hall B, 8 Hall A) and the IEF3 PicoBlade 51021-0600 (2 I, 3 GND, 4 5 V, 5 B, 6 A).

## Measure on the robot before ordering

Tracked in `docs/open-issues.md` (M13–M18):
1. How the widened brackets are fixed now, and the distance from the deck's M4 holes (46.4 mm from the centreline in the kit model) to the bracket inner face (assumed 71.0 mm: 142 / 2). Parameter `HALF_GAP`, `FOOT_HOLES`.
2. Wheel axle height above deck 1's top (model: 15.3 mm) and the deck plate edge (model: 60.3 mm from the centreline). `AXLE_Z`, `PLATE_EDGE`.
3. Wheel: distance from the bracket's inner face to the wheel's inner rim face (model 8.8 mm) and to the bottom of the hex socket (17.9 mm). `WHEEL_INNER`, `HEX_FACE`.
4. Free space under deck 1 at the foot (40 × 30 mm under each rear corner) and around the plate edge.
5. maxon's Hall board outline: confirm in the maxon STEP (configurator "Create CAD data" for B845D2FFA4A0) that with the board up it stays below R17. `MOTORS["maxon"]["tab"]`.
6. Rear track after the widening (wheel centre to centre, model: 188.8 mm); the rear wheels now stand 7 mm outside the bumpers (`Footprint` half width).

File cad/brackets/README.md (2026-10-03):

# Rabbit 2.0 printed mounts

Brackets and holders for the Rabbit 2.0 sensors (`docs/reports/2026-10-03-architecture-2.0*.md`) and for the body PCB (`docs/reports/2026-10-03-body-pcb.md` §10), designed for a Bambu Lab P2S (256 × 256 × 256 mm, enclosed). Every part is a build123d script with its parameters at the top; the STEP is the part as installed on the robot (chassis frame), the 3MF is the part in its print orientation, ready for Bambu Studio.

```bash
cd cad/brackets
uv run --project ../../model python tof_pair.py        # any part: writes <part>.step and <part>.3mf
uv run --project ../../model python assembly.py        # fit checks, renders/, rabbit-2.0-mounts.step
```

`assembly.py` imports `model/chassis.step` once (~1 min) and caches it under `data/cad/chassis/` (gitignored); it also reads `pcb/rabbit-body/rabbit-body.step`. A full run takes ~20 min; `--no-render --no-step` gives the checks alone, `--step-only` just the combined STEP. The checks land in `renders/fit_report.json`. The combined STEP (~36 MB, the PCB included) leaves out the kit's fasteners (their modelled threads are ~1 MB each) and shows the tyres as envelopes.

Frame: `model/chassis.step`, mm. Forward is −Y, the robot's left is +X, up is +Z, plate centreline x = 2.48, rear axle y = 83.15. Heights "above the floor" use the floor of the PCB report (front tyres, deck 1 top at 24.8 mm). The PCB's own frame (+X right, +Y forward) maps as x = 2.482 − X, y = −3.427 − Y.

## The stack

| Deck | What | Height above the floor |
|---|---|---|
| 1 | lower kit plate: motors, servo, Jetson, bumpers, ToF pairs | top 24.8 |
| — | 4 × brass M3 F-F 45 mm | |
| 2 | body PCB (`pcb/rabbit-body`), 1.6 mm, all parts on top | bottom 69.8, top 71.4 |
| — | 4 × brass M3 F-F 45 mm on the same columns | |
| 3 | upper kit plate: V-mount plate + battery, ZED, lidar mast, button pod, rear camera | bottom 116.4, top 118.4 |

assembly

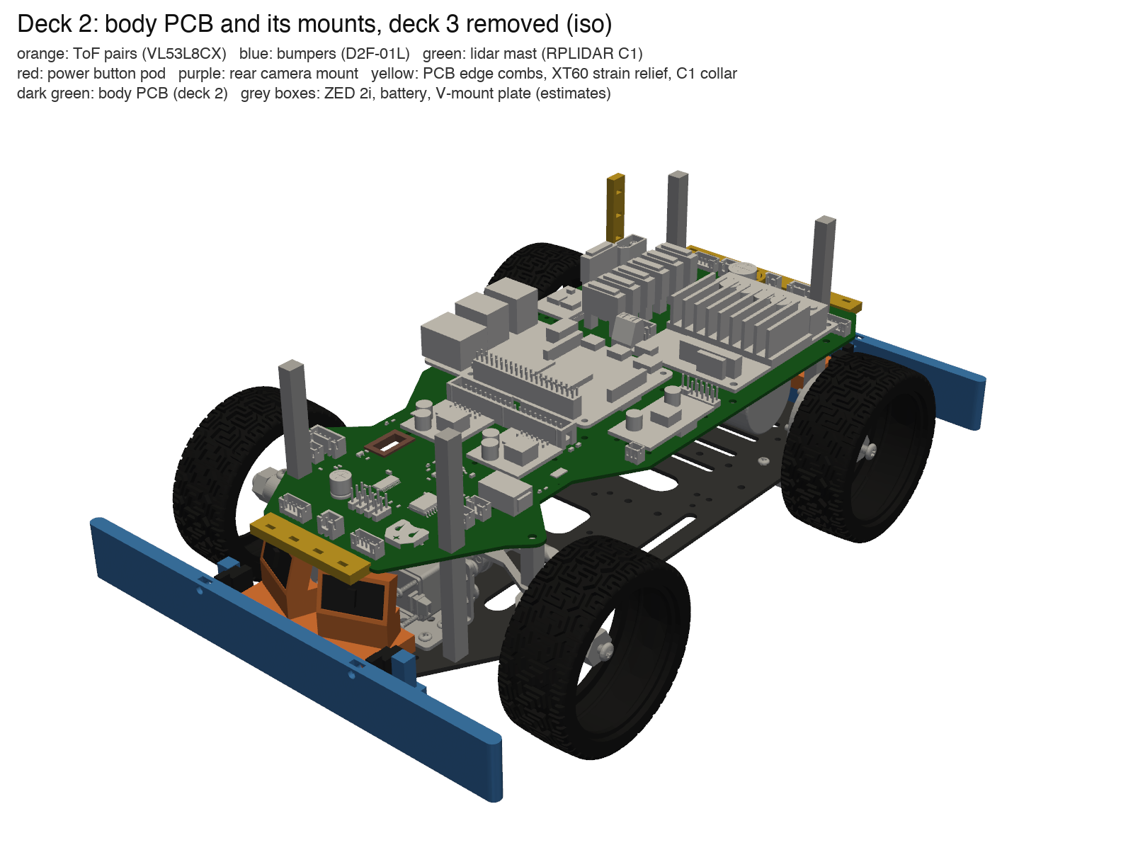
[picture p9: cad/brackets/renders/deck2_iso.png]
deck 2


## Parts

| Part | Qty | Material | Orientation on the plate | Walls / infill | Supports | Est. time, filament |
|---|---|---|---|---|---|---|
| `tof_pair` (front and rear are the same print) | 2 | PETG | foot down, as exported | 4 walls, 30% gyroid | no | ~50 min, ~15 g each |
| `bumper_front` | 1 | PETG | plate side down, as exported (leaves stand vertical) | 3 walls, 25% gyroid | no | ~1 h 15, ~30 g |
| `bumper_rear` | 1 | PETG | as `bumper_front` | 3 walls, 25% gyroid | no | ~1 h 20, ~32 g |
| `lidar_mast` | 1 | PETG (ASA if the robot works in sun) | foot down | 4 walls, 30% gyroid | no | ~1 h 45, ~38 g |
| `power_button_panel` | 1 | PETG | button face down, as exported | 3 walls, 20% | no | ~35 min, ~11 g |
| `rear_camera_mount` | 1 | PETG | foot down | 4 walls, 30% | no | ~20 min, ~5 g |
| `pcb_comb_front` | 1 | PETG | under-board flange down | 3 walls, 100% | no | ~10 min, 2.5 g |
| `pcb_comb_rear` | 1 | PETG | under-board flange down | 3 walls, 100% | no | ~15 min, 4.5 g |
| `xt60_strain_relief` | 1 | PETG | clip down, post up, as used | 3 walls, 100% | no | ~10 min, 2 g |
| `cap_clamp` | 1 | PETG | standing | 3 walls, 100% | no | ~5 min, 1 g |
| `zed_grommet` | 1 | TPU 95A | flange down | 100% | no | ~5 min |
| `slot_grommet` | 2 | TPU 95A | flange down | 100% | no | ~5 min each |
| `cable_clip` | 6 | PETG | on its side, as exported | 3 walls, 100% | no | ~3 min, 0.5 g each |

Times and weights are estimates from the part volumes; slice for real numbers. Common settings: 0.4 mm nozzle, 0.2 mm layers, Bambu PETG HF profile, textured PEI plate (or glue stick on smooth PEI), no brim needed. TPU: Bambu TPU 95A profile, slow.

**The bumper leaves are the springs.** They are 1.25 mm thick, which is exactly three 0.42 mm lines: keep wall loops at 3 so each leaf is solid perimeters with no infill or gap fill. The leaves stand vertical in the print, so the layers run along the bending direction and do not split. Don't print the bumpers in PLA: the springs creep.

Slicer checks (build123d MCP `analyze_printability`, 45° support angle): no part needs supports. The remaining findings are short bridges: the 4 mm insert holes and the horizontal M2 pilots, the 6 mm screw bores under the lidar platform, the 1 mm lips of the PCB clips, and a 13 mm tilted ceiling plus 5 mm ledges inside each ToF board pocket (hidden behind the board).

### P2S plates

| Plate | Parts | Time |
|---|---|---|
| A, PETG, test fit | 2× `tof_pair`, `rear_camera_mount`, `power_button_panel`, `pcb_comb_front`, `pcb_comb_rear`, `xt60_strain_relief`, `cap_clamp`, 6× `cable_clip` | ~3 h |
| B, PETG | `bumper_front` and `bumper_rear` side by side along X (204 × 35 mm each), `lidar_mast` | ~4 h 20 |
| C, TPU | `zed_grommet`, 2× `slot_grommet` | ~15 min |

## Hardware

### Buy (not printed)

| Item | Qty | Where |
|---|---|---|
| Brass standoff M3 F-F **45 mm**, hex | 8 | deck 1 → PCB and PCB → deck 3, on the four kit columns (PCB report §10, items 1–2); M3 × 6 screws + washers (the plate holes are 4.3 mm) |
| Standoff M3 **18 mm** | 2 | steering bracket to the PCB at the kingpins (§10 item 3; the kit's were 23 mm) |
| Standoff M2.5 × 6 mm + M2.5 × 6 screws | 4 | Raspberry Pi 4 on the PCB (§10 item 4) |
| Standoff M3 × 6 mm + M3 × 6 screws | 4 | RoboClaw on the PCB (§10 item 5) |
| Heat-set inserts M3 × 5.7 (hole 4.0 mm) | 18 + spares | the printed parts below; press at 220–230 °C |
| Cable ties 3.6 mm | ~20 | combs, strain relief, clips |

Screw lengths assume the kit's 2 mm plates.

| Where | Screws | Inserts / nuts |
|---|---|---|
| bumper → deck 1, per bumper | 3× M3 × 8 from under the plate; washer on the one in the 5.4 mm slot (rear) | 3 inserts in the pad |
| ToF pair → bumper backbone, per pair | 3× M3 × 12 from under the backbone | 3 inserts in the foot |
| VL53L8CX board → ToF pair | 2× M2 × 6 self-tapping per board (8 total) | 1.7 mm pilots |
| D2F-01L → bumper switch post | 2× M2 × 10 + M2 washers per switch (8 total) | 1.7 mm pilots |
| bumper striker (one per switch) | M3 × 12 grub screw (4 total) | M3 hex nut in the slot in the bar |
| lidar mast → deck 3 | 2× M3 × 8 (3.2 mm holes) + 2× M2.5 × 10 self-tapping (2.7 mm holes), from under deck 3 | 2 inserts in the foot bosses |
| RPLIDAR C1 → mast | 4× M2.5 × 8 from below; **no more than 4 mm into the lidar** (Slamtec) | — |
| power button pod → mast | 2× M3 × 8, through the access holes in the pod's outer wall | 2 inserts in the mast wall |
| rear camera mount → deck 3 | 2× M3 × 8 + washers, from under deck 3 through the rear slot | 2 inserts in the foot |
| Camera Module 3 Wide → mount | 4× M2 × 6 self-tapping | 1.7 mm pilots |
| cable clip | M3 × 8 + nut each | — |
| PCB combs, XT60 strain relief | push-on; a drop of CA if loose | — |
| C1 collar | CA or hot glue to the board and the capacitor (the board has no holes for it) | — |

## How each part works

### ToF pair (`tof_pair.py`)

Two VL53L8CX on Pololu #3419 carriers (12.7 × 22.86 mm, M2 holes 17.78 mm apart, from Pololu's dimension drawing), one pair per end, on the bumper backbone. Each board is yawed 22° outward (the 2.0 design), so the two 45° × 45° fields cover −44.5…+44.5° around the robot axis, and pitched **15° up**. The sensors are 57.8 mm above the floor, so the lowest zone row meets a flat floor only ~0.44 m away: the 0–0.4 m blind zone the ToFs exist for is free of floor returns. The price is that low things right in front are not seen (at 0.1 m only above ~45 mm, at 0.3 m above ~18 mm); the bumper bar covers 25–49 mm.

**The boards lie landscape** (long side horizontal, the 9-pin row at the bottom). The PCB nose and tail pass over the heads, and its connectors' THT pins reach 1.8 mm below it, so the heads had to come down: the gap from the head tops to the lowest PCB feature is 3.5 mm at the front and 2.7 mm at the rear. The sensor's zone grid is turned 90°, so `T_base_tof` needs that roll.

Boards face out in a pocket sized for wires soldered straight to the pads (no straight headers): the pocket behind the board is 4.5 mm deep. Wires (VIN, GND, SDA, SCL; tie SPI/I2C to GND on the board) drop through the column and leave at the back of the foot. From there they run forward along the foot, out past the PCB edge, up over the edge comb (tie them there) into J8/J9 (front) and J10/J11 (rear). Run them as twisted pairs with ground, ≤ 40 cm (`-wiring.md`).

Poses for `T_base_tof` (from the rear axle, robot frame x forward, y left): front sensors 224.6 mm ahead, ±19 mm off the centreline, yaw ±22°; rear sensors 51.4 mm behind, ±19 mm, yaw 180 ∓ 22°; all 57.8 mm high, pitch +15°, roll 90°.

### Bumpers (`bumper.py`, `bumper_front.py`, `bumper_rear.py`)

One PETG print per end. A pad bolts to deck 1; in front of the plate edge a backbone carries a central stub, from which a 1.25 mm leaf runs 40 mm to each side. The leaf tips carry the bar (204 × 6 × 24 mm, 25–49 mm above the floor) on two posts. A push anywhere on the bar moves it back; an off-centre hit also turns it, which drives the nearer switch further. Spring rate ~0.7 N/mm for the bar (two guided 40 × 1.25 × 6 mm PETG leaves), so a switch trips at ~2 N; at the stops a leaf sees ~16 MPa, a third of PETG's yield.

Each Omron D2F-01L stands upright on a post on the backbone, lever toward the bar, and is struck by an M3 grub screw threaded through a nut trapped in the bar. Hard stops on the backbone end the travel at **3.5 mm**: the lever's operating point is 6.8 ± 1.5 mm and overtravel ≥ 0.55 mm (Omron datasheet), so set each grub screw so its switch clicks after ~1.5 mm of bar travel; the remaining 2 mm is taken by the springy lever. Wire the two NC contacts in series to J13 (front) / J14 (rear).

The bar is set so that, pushed to the stops, it stays clear of the front tyres at full steering lock (see Checks). It sits below the ToF fields of view and far below the ZED's, and the whole bumper is below the PCB.

**The footprint grows:** front 0.2452 m from the rear axle (was 0.2245), rear 0.072 m (was 0.07), half width 0.102 m (was 0.10). `Footprint` in `workspaces/rabbit/src/lib/safety.py` and `front_overhang` in `lib/planner.py` must change when the bumpers go on.

### Lidar mast (`lidar_mast.py`)

RPLIDAR C1 (Slamtec datasheet v1.0, fig. 4-1: 55.6 mm square base, 41.3 mm tall, laser plane 29.8 mm above the base, 4× M2.5 in a 43 mm square, ≤ 4 mm deep). The mast stands on deck 3 in the strip between the ZED and the V-mount plate. The 2026-10-03 side photo shows the owner's V-mount plate running from ~26 mm to ~180 mm from the deck's rear edge, so the mast sits in front of it: lidar centre on the centreline 159.7 mm ahead of the rear axle, foot 40–81 mm behind deck 3's front edge.

**Scan plane: 230 mm above the floor** (lidar base 200.2 mm, mast 81.8 mm, robot top 241.5 mm). Why: deck 3 is at 118.4 mm, the V-mount plate is ~17 mm thick in the photo, and the PS099E is 56.7 mm, so the battery top is ~192 mm. The lidar base sits 8 mm above that, so the pack slides out under it. The plane then clears the battery by 38 mm, far more than the C1's scan-field flatness (0–1.5°, 5 mm at 0.2 m) needs. That is 1 cm above the report's 18–22 cm range, because the real battery stack is taller than the 2.0 report assumed. The check sweeps a band of ±(3 mm + r·tan 1.5°) from 31 to 500 mm around the lidar against every solid of the model, the PCB included: nothing is in it.

The tube is hollow; a 45° flare carries the platform. Screw the C1 on with M2.5 × 8 from below through the 6 mm bores in the flare. Cable: mount the C1 with its cable side forward. The C1's 0° points away from the cable (datasheet v1.0, fig. 2-4), so `T_base_lidar` yaw is 180°, the `rabbit-lidar` default; check the sign on the first scan. Run the lead into the window under the flare at the front, down inside the tube, out through the window at the −X foot and down through the left deck 3 slot (with the ZED cable) to J12 on the PCB nose.

### Power button pod (`power_button_panel.py`)

A pod on the +X (robot-left) side of the mast, on the mast's foot, for a 16 mm two-pole (2NO) momentary metal button with a 5 V ring LED (BOM item 6) and a 5 mm status LED (GPIO19). The button face is 164 mm above the floor and just outboard of the lidar base, so a finger reaches it from above. The pod is open toward the mast and the foot: fit the button and its nut first, then screw the pod to the mast through the access holes in its outer wall. Wires drop through the opening in the mast foot and the right deck 3 slot (with its grommet) to J15/J16 on the PCB nose. For a 19 mm button, set `BUTTON_HOLE = 19.2` and widen the pod (`X1`).

### Rear camera mount (`rear_camera_mount.py`)

Camera Module 3 Wide (official mechanical drawing: board 25 × 23.862 mm, M2 holes 21 × 12.5 mm apart, 2 mm from the edges, lens 14.4 mm above the bottom edge, 102° × 67°). On the rear edge of deck 3, 10 mm behind the V-mount plate. The lens is 138 mm above the floor, 59.6 mm behind the rear axle, pitched 15° down: the floor is visible from ~0.12 m behind the lens, and neither the plate, the bumper nor the ToF pair is in view (checked with the frustum). A window behind the board leaves room for the FPC connector.

The 300 mm ribbon runs down behind the plate, over deck 3's rear edge and down to the Pi's CSI connector. The PCB report routes it up through deck 3's long slot at y 51 instead, but that slot is under the V-mount plate.

### PCB edge combs (`pcb_edge_comb.py`, §10 items 8 and 9)

C-clips that push onto the PCB's front (nose, 50 mm) and rear (92 mm) edges. Each grips 3.5 mm under the board, clear of the edge connectors' THT pins 4.5 mm in, and 1 mm on top, clear of the connector bodies. A 7 mm flange outside the edge carries cable-tie slots for the ToF, bumper and encoder cables that go over the edge to deck 1. The flanges are 2.9 mm above the ToF heads.

### XT60 strain relief (`xt60_strain_relief.py`, §10 item 7)

A clip on the PCB's right edge at board Y −110 with a post outside the edge, rising to 4 mm under deck 3, with three tie slots. Tie the battery lead (from the V-mount plate, down past the right rear corner into J1 from above) to it so a pull never reaches the XT60. The post is 3.7 mm inboard of the rear right tyre.

### C1 collar (`cap_clamp.py`, §10 item 6)

A 10 mm ring around the 1000 µF capacitor (Ø12.5 × 25 mm, standing), open toward J7/J14. Glue it to the board and the can; it stops the can rocking on its leads on impacts.

### Grommets (`zed_grommet.py`, `slot_grommet.py`, §10 item 11 and the deck passthroughs)

TPU 95A, push-in with a snap lip.
- `zed_grommet` lines the PCB's 7.8 × 13.8 mm ZED cutout. It leaves 6.2 × 12.2 mm, enough for the USB-A plug straight through.
- Two `slot_grommet`s line deck 3's 10.3 × 23.9 mm slots at (∓25.7, −70.3), so the aluminium edges don't cut the cables. Left: ZED USB 3 and the lidar lead. Right, inside the mast foot: the button and LED wires.

### Cable clip (`cable_clip.py`)

Snap-in clip for bundles up to 6.5 mm on any 3.2 mm plate hole, M3 screw and nut.

### Not made

- **USB hub bracket (§10 item 12).** Waveshare's outline drawing gives the hub as 72.2 × 47.8 × 27.6 mm, 86 mm with its mounting ears, with ports on both long sides. Under deck 3 it would leave at most 17.4 mm above the PCB, where §10 asks for ≥ 20 mm and the parts below reach 14 mm. In the place §10 suggests (board X −20…20, Y 35…125) it also sits over both deck 3 cable slots and against the front deck columns, and its plugs need ~35 mm on each long side. The hub needs a new place (decision for the owner and the PCB design, `docs/open-issues.md`).
- **Wi-Fi antenna mount.** The Alfa AWUS036ACM is 62 × 85.3 × 24 mm with two RP-SMA jacks on the body, and its 5 dBi antennas are ~19 cm long: upright they would cross the scan plane and shadow ~3° each. Keep the tips below 220 mm (stubby antennas, or tilt them) or mask the sectors in `rabbit-lidar`.
- **Printed spacers between decks:** brass, see "Buy".

## Checks (`assembly.py`)

The model is the kit with the robot's stack rebuilt:
- deck 3 on 45 + 45 mm columns (lifted 41.6 mm from the kit);
- the PCB STEP as deck 2;
- the steering posts cut to 18 mm under the PCB;
- boxes for the ZED 2i (175.3 × 43.1 × 30.3 mm, back face 23 mm behind deck 3's front edge, from the photo), the V-mount plate (90 × 154 × 17 mm, from the photo) and the battery (73 × 111 × 56.7 mm, NEEWER spec).

| Check | Result |
|---|---|
| Every plate screw lands in a measured plate hole or slot of the right size (12 screws) | all 12 match |
| Overlap of every printed part and every piece of hardware with each other, with the 134 chassis solids, with the 266 solids of the PCB STEP and with the envelopes | none above 0.5 mm³ |
| Gap from the deck-1 parts to the PCB and its pins | ToF pairs 3.5 mm (front) / 2.7 mm (rear); ToF boards 5.9 / 4.6 mm; bumpers and switches nowhere near |
| Front tyres (Ø74.9 × 29.2 mm envelopes) steered about the measured kingpins to ±35° and ±40°, against the bumper (bar at rest and pushed 3.5 mm), switches and ToF pair | smallest gap 4.5 mm (bumper at 40°), 7.2 mm for the pushed bar |
| ToF fields (45° × 45°, 0.6 m) against all solids | clear for all four |
| Lidar band (above) | clear |
| ZED 2i field (110° × 70°, 1.5 m, level and pitched 10° down) | clear |
| Rear camera field (102° × 67°, 1 m) | clear |

Renders:
- `renders/assembly_{iso,iso_rear,top,side,front,rear}.png`;
- deck 2 with deck 3 removed: `renders/deck2_{iso,top,side}.png`;
- details: `renders/detail_{front,rear,mast}_*.png`;
- fields of view: `renders/fields_of_view_{iso,side,top}.png`;
- each part alone: `renders/part_*_{iso,iso_rear}.png`.

## Measure before printing

The tracker for these is `docs/open-issues.md` (M-items). Each names the parameter to change.

1. **Column lengths**: 45 + 45 mm, so deck 3 at 118.4 mm. `STANDOFF_1_2`, `STANDOFF_2_3` in `common.py`; the mast height follows.
2. **Battery top** above the floor with the V-mount plate (assumed ~192 mm): must stay below the lidar base (200.2 mm), else raise `LIDAR_PLANE_H`.
3. **Free strip on deck 3 between the ZED and the V-mount plate**: the mast foot covers 40–81 mm behind deck 3's front edge. Assumed from the photo: ZED back face (with the USB plug) at 23 mm, V-mount front at 90 mm.
4. **Rear end of deck 3**: the camera foot needs the last 15.5 mm, ±16 mm of the centre, and the 5.4 mm slot there free; the V-mount plate is assumed to end 25 mm before the rear edge.
5. **Deck 1 front strip**: the 14 mm in front of the steering-servo bracket must be free (slot 4.6 mm and hole 10.85 mm from the front edge). **Rear strip**: free behind the rear corner columns (holes 7 mm from the rear edge).
6. **THT leads under the PCB nose and tail** (J8, J9, J13, J6, J7, J11, J14): trim to ≤ 1.5 mm; the ToF heads are 2.7 mm below the longest ones.
7. **Steering lock**: checked to ±40° about the kit's kingpins. If the real lock is larger, re-run `assembly.py` with `STEER_LOCK_CHECK` raised.
8. **Your power button**: body behind the panel ≤ 37 mm, nut ≤ 21 mm across corners, panel ≥ 2.5 mm allowed.
9. **ToF wiring**: the pocket assumes wires soldered to the pads; straight header pins (6 mm) will not fit.
10. **Camera FPC connector**: the window behind the board is 14 × 16 mm at its centre; check against your module.

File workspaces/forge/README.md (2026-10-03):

# Forge

Forge turns the telemetry of Rabbit, a small rover (this monorepo), into answers an agent can trust. It records every NATS stream, every command with its sender, the robot's configuration changes and the logs of all its nodes into Parquet files on one clock, tagged by run, queries them with chDB (ClickHouse embedded in the Node process), keeps a library of reviewed queries called **slabs**, guards every ad-hoc query with a static SQL gate and an EXPLAIN, and serves all of it to coding agents over MCP, plus an `ask` agent that answers questions in plain language.

It is a small, standalone version of the ideas behind Sherpa in Nexus: curated queries with grain and measure metadata, a fast path that runs a reviewed query, and a heavy path where a sub-agent writes new SQL that must pass validation before it runs.

## Architecture

```
Rabbit (NATS 192.168.1.53:4222)
  │  rabbit.roboclaw, rabbit.ina, rabbit.steering, rabbit.zed.{imu,pose,magnetometer,barometer},
  │  rabbit.zed.obstacle, rabbit.nav.{state,goal,mission,cancel,explore}, rabbit.cmd.{drive,joy},
  │  rabbit.explore.state, rabbit.operator.heartbeat, rabbit.map.{chunks,save},
  │  rabbit.health.zed, rabbit.telemetry
  │  JetStream: LOGS (rabbit.log.>, durable, 7 days on the robot), KV_rabbit (camera settings and other config)
  ▼
writer ── one Parquet file per table and hour every 10 s (temp file, fsync, rename) ──► data/<table>/date=…/hour=…/*.parquet
       logs: durable pull consumer, acked after the file is committed       compaction: hourly files; retention
                                                                          ▲ chDB views forge.<table> = file(glob, Parquet, schema)
CLI ─┬─ run start / stop / list                                           │
     ├─ slab list / search / run / check  ────────────────────────────────┤
     ├─ query (static gate + EXPLAIN)  ───────────────────────────────────┤
     └─ ask ── fast path: search_slabs → run_slab                         │
             └ heavy path: write_query → SQL sub-agent → finalize (gate + EXPLAIN) → run
MCP server (stdio): list_runs, search_slabs, run_slab, query, describe_schema, detect_anomalies, metric_graph, investigate,
                    timeline, search_logs, logs_around, list_metrics, ask
detect_anomalies ── resample in ClickHouse ──► tsfm.ai (Chronos-2, joint targets, graph-picked covariates) + run-wide reference
investigate ── graph/metrics.yml upstream walk ──► per-link anomaly, co-movement and lead-lag scores ──► ranked causal chains
```

One service, `forge`, runs the writer, the compaction and the chat API in one Node process (`node src/cli.ts serve --writer`) with `restart: unless-stopped`. There is no database server: the writer writes Parquet files into the `forge-data` volume and every query runs in chDB inside the same process. The image (`Dockerfile`) is Node from `.nvmrc` on Debian slim, because chDB ships only glibc builds (`@chdb/lib-linux-arm64-gnu`, about 500 MB unpacked), with production dependencies installed from the lockfile and no secrets. Node runs with `--liftoff-only`: the SQL gate's parser is a 25 MB WebAssembly module, and V8's optimizing tier kept about 170 MB of compiled code for it; the baseline compiler costs nothing measurable (0.77 instead of 0.70 ms per query) and keeps about 30 MB.

## Run it

In normal use Forge runs on the robot itself: `forge` is a service in the monorepo's `workspaces/compose.yaml`, deployed with `scripts/deploy.sh`, and the HUD reaches the chat through `https://jetson.rabbit/api`. On the Mac the CLI, the MCP server and the evals read a mirror of the robot's Parquet files (see Storage). The commands below also run the whole service on a laptop for development.

Requires Node 26 (`.nvmrc`), pnpm and Docker.

```sh
pnpm install
pnpm forge sync                      # mirror the robot's Parquet files into data/forge (FORGE_SYNC_FROM)
docker compose up -d --build --wait  # optional: the whole service on the laptop, chat on 127.0.0.1:18080, its own data volume
docker compose logs -f forge         # rows/s every 10 s, with the NATS state (connecting, connected, disconnected)
pnpm forge run start --name hard-launch --note "five full-throttle starts"
pnpm forge run stop
pnpm forge run list
pnpm forge slab run battery_sag --param bucket_s=5
pnpm forge query "SELECT max(temp_tj) AS tj FROM jetson WHERE run_id = {run_id:String}" --param run_id=latest
pnpm forge detect battery_voltage,motor_current --param run_id=latest --param "from=2026-10-01 11:02:30" --param "to=2026-10-01 11:06:00"
pnpm forge graph motor_current --param hops=2
pnpm forge investigate reboots --param at=11:00
pnpm forge ask "What was the average battery voltage and total motor current in the last run?"
```

The writer starts without the robot: it removes files a crash left unfinished, then keeps reconnecting to NATS every 2 s until the robot is up, and reconnects indefinitely after a drop. The healthcheck asks `/api/health` whether the embedded engine answers. Rows that cannot be stored land in `dead_letters/`.

`pnpm forge serve` alone serves the chat on the laptop over the mirror; never run a second writer against the robot's NATS with the same log consumer (`FORGE_LOG_CONSUMER`, default `forge`): two writers would split the log stream between them.

`ask`, `write-query` and `serve` need `OPEN_AI_KEY` in `.env`, and `detect` needs `TSFM_KEY` (see `.env.example`). When `.env` exists Forge reads every setting from that file only, never from the shell environment; without it (the containers, which receive `.env` through `env_file`) it reads the process environment. Settings: `FORGE_DATA_DIR` (default `data/forge` at the repository root; `/app/data` in the container), `FORGE_SYNC_FROM` (the robot's data directory over SSH; set on the Mac, empty on the robot), `FORGE_MAX_DATA_GB` (size cap, default 50), `FORGE_LOG_CONSUMER` (default `forge`), `FORGE_NATS_URL` and `FORGE_CHAT_LISTEN_HOST` (default `127.0.0.1`; the container listens on `0.0.0.0`). The agent uses OpenAI `gpt-6-luna` with low reasoning effort through the Vercel AI SDK.

Ingest: the writer subscribes once per subject and parses each message once, buffers rows in memory and every 10 s writes one Parquet file per table and hour (see Storage). A write retried after a transient error (disk full, a file error, memory) reuses its file id, so it replaces its own file and never duplicates rows; the first failure of a batch is logged and retries back off up to 30 s. A batch the engine rejects is split in half until the bad rows are isolated. Those rows, anything unsent 10 s into shutdown, and buffer overflow go to `dead_letters/<table>.jsonl`: at most 1 M rows wait in memory across all tables, and beyond that the oldest tenth of the cap is taken from the largest table at once.

## Storage

Each table is a directory of Parquet files, `data/<table>/date=YYYY-MM-DD/hour=HH/<from>-<to>.parquet`, partitioned by the hour of the row's `ts` (`at` for `run_events`), zstd-compressed, sorted by the table's `ORDER BY`, with row groups of 65,536 rows. `src/store/schema.sql` is the schema: the CREATE TABLE statements (types, defaults, comments, sort key) are created in an in-memory `forge_schema` database at start, and every table becomes a view `forge.<table>` = `SELECT * FROM file('<table>/*/*/*.parquet', Parquet, '<columns with their exact types>')`, so slabs, the graph, the tools and the agent's SQL keep the ClickHouse dialect and the table names. Old files that lack a column read it as its type's default (`input_format_parquet_allow_missing_columns`). Engine settings and the reader limits are in `src/store/engine.ts`.

- **Writing.** A batch goes through an in-memory staging table (`ENGINE = Memory`, built from the schema, so DEFAULT and MATERIALIZED columns such as `imu.g` and `logs.fingerprint` are computed as before), then `INSERT INTO FUNCTION file('<name>.parquet.tmp', Parquet)`, `fsync`, `rename` and an fsync of the directory. Readers glob `*.parquet`, so they never see an unfinished file, and a hard power-off loses at most the last 10 s that were still in memory. The file name is the writer's flush id (milliseconds, strictly increasing across restarts).
- **Freshness.** Rows are queryable once their file is committed, at most 10 s after they arrive, as with the old ClickHouse inserts; there is no in-memory tail to merge.
- **Compaction** (every minute, in the writer): a closed hour (2 minutes past its end) is merged into one file; an open hour merges its 10 s files once 30 have piled up. The merged file is named after the range of ids it covers, `<from>-<to>.parquet`. Tables declared `ReplacingMergeTree` in the schema (`logs`, `kv_changes`) drop duplicate sorting keys while merging, which is when ClickHouse used to drop them. Renaming the merged file and deleting its inputs happen under a lock that queries in the process share, so a query never sees both; after a crash between the two, the next start deletes every file whose id range lies inside another file's (`recover`).
- **Retention** (hourly): `logs` older than 30 days keep only warnings and worse, and are dropped after 180 days; above `FORGE_MAX_DATA_GB` the oldest hours of the other tables are dropped until the store is under 90 % of the cap. `run_events` is never dropped.
- **Reading.** chDB runs in the process: one writer session and four reader sessions (`readonly=2`, 30 s, 300 MB per query with sorting and GROUP BY spilling to disk above 100 MB, 200 M rows or 4 GB read, 10k result rows, two threads), a 900 MB cap for the engine as a whole. Queries are served by the next free session, so a slow one does not block the others.
- **The Mac.** `pnpm forge sync` rsyncs the robot's files (`FORGE_SYNC_FROM`, over SSH with `~/.ssh/rabbit_id_rsa`) into `FORGE_DATA_DIR` and removes merge inputs a sync caught mid-compaction. With `FORGE_SYNC_FROM` set, the CLI, the MCP server and the evals sync on their own before a query when the copy is older than 30 s; when the robot is off they query the last copy. Starting and stopping runs from the Mac goes to the robot's writer over NATS (`forge.run.start`, `forge.run.stop`).
- **Maintenance commands.** `pnpm forge compact` merges and applies retention once; `pnpm forge import <dir> --before '<UTC time>'` loads `<table>.parquet` exports (the migration from ClickHouse), replacing the store's rows before that time; `pnpm forge bench [<run id>]` times the heaviest tool queries and reports memory.

## Runs

A run is one recording session; every row carries its `run_id` (`20261001-100306-bench-idle`). `forge run start` and `forge run stop` append events to `run_events`; the `runs` view folds them into one row per run. The writer polls for the open manual run every two seconds and tags rows with it. When no manual run is recording, the writer opens an **auto** run so no data is untagged, and closes it after 60 s without messages or when a manual run starts. `run_id = 'latest'` resolves to the most recent manual run.

## Schema

`src/store/schema.sql`, one table per stream, `ORDER BY (run_id, ts)`, `ts` the robot wall clock as `DateTime64(9, 'UTC')`. Column comments carry units and caveats, and `describe_schema` serves them to agents. To add a column, add it to the schema and to `src/streams.ts`; files written before read it as its type's default.

| Table | Rate | Contents |
| --- | --- | --- |
| `roboclaw` | 50 Hz | per side (`left` = M1, `right` = M2) command, pwm, current, speed, encoder; 12 V `supply_voltage`, `duty_max` (voltage cap), temperature, status, errors, serial retries and reconnects |
| `power` | 50 Hz | INA4235: `battery_*` (99 Wh 4S Li-ion, 16.8 V full) voltage, current, power, `battery_charge_pct`, `battery_clipped`; `rail_6v_*` servo rail with `rail_6v_clipped` |
| `steering` | 20 Hz | angle, pulse width, failed servo writes |
| `imu` | ~100 Hz | acceleration, angular velocity, orientation, `g` |
| `magnetometer`, `barometer` | 50, 25 Hz | field and heading; pressure |
| `pose` | 30 Hz | position, orientation, Euler angles, velocity, position std, confidence |
| `zed_health` | 1 Hz | fps, dropped frames, tracking state and quality flags, relocalizing, map mode, map id and session, pose filter counters, nvblox timings, floor, tilt, temperatures; rabbit-loc shadow check (`loc_status`, `gen3_from_loc_*`) |
| `loc` | per keyframe, 1 Hz | rabbit-loc `map←odom` (RTAB-Map): status, mode, map id, odom session, translation and yaw, matches, corrections, grown nodes |
| `jetson`, `jetson_containers` | 1 Hz | per-core load, requested and actual clocks, clock floors, EMC clock, over-current counters, temperatures, rail power, fan; per-container CPU and memory |
| `joy` | 30 Hz | gamepad throttle and steer while connected (receive time) |
| `operator_heartbeat` | 2 Hz | HUD heartbeats (HUD time) and their round trip through the robot back to Forge |
| `wifi` | 1 Hz | Wi-Fi signal, router ping, link rates, throughput, errors and drops |
| `map_chunks` | on change | spatial-map mesh chunk vertex and triangle counts and centroid; the mesh is not stored |
| `obstacle` | 10 Hz | nearest obstacle and nearest obstacle in the driving corridor: distance, bearing, point; the governor's scan and blind flag |
| `nav_state` | 10 Hz | navigation mode, goal, mission step, distance to goal, heading error, speed, steer, free distance, safety fault, hold reason, mission id and source, trip id |
| `drive`, `nav_events` | 20 Hz, events | drive commands; goals, missions and cancels; each with its `source` (nav, explore, forge, hud) |
| `command_events` | events | exploration starts and map saves with their sender and payload |
| `explore_state` | 2 Hz | exploration id, phase, limits, distance driven, frontiers, target, planning time |
| `planner_state` | 2 Hz | route planner trips (go_to, explore): trip id, phase, target, goal viewpoint, route length and metres left, replans, recoveries, last replan reason, status message |
| `kv_changes` | on change | changes of the robot key-value bucket: camera settings, intrinsics, operator and UI state (current values at writer start) |
| `logs` | events | log records of every node (see Logs) |
| `events` | events | every decision and state change of the nodes with its reason, ids and measured values (see Events) |
| `node_starts` | per start | code revision and source hash, package versions, environment and every constant in effect when a node started |
| `node_metrics` | 0.1 Hz | per node: CPU, RSS, threads, event-loop lag, NATS messages and bytes, dropped publishes, log and event drops, callback errors, loop timings |
| `nats_server` | 0.2 Hz | robot NATS server: connections, subscriptions, slow consumers (message loss), messages and bytes, memory, CPU |
| `safety_state` | 10 Hz | Rabbit 2.0 body safety loop: mode, binding reason, requested vs allowed command, caps and clearances forward and in reverse, E-stop line, self-test, bumpers, input ages |
| `power_state` | 1 Hz, on change | Rabbit 2.0 power supervisor: shutdown state machine state and reason, battery, Jetson current, brain and safety readiness |
| `lidar_health` | 1 Hz | RPLIDAR C1: scan rate, points per rotation, rotation time, bad nodes, restarts, device health, nearest return per 30° sector |
| `tof_health` | 1 Hz per sensor | VL53L8CX ×4: state, frame rate, valid, floor and overhead zones, obstacle zones, nearest obstacle, errors, resets, power cycles |

The JPEG preview (`rabbit.zed.frame.preview`) and the map snapshot reply (`rabbit.map.snapshot`) are not stored; `zed_health` carries the preview counters and `map_chunks` the mesh summaries. The Rabbit 2.0 body streams are summarised too: full lidar scans (`rabbit.lidar.scan`, binary, 10 Hz, ~2 kB, ~70 MB/h raw, several times the whole store today), ToF frames (`rabbit.tof`, 4 × 15 Hz) and the 50 Hz `rabbit.safety.drive` are not stored; `lidar_health` keeps the nearest return per sector every second, `tof_health` the zone counts, `safety_state` the allowed command with its clearances at 10 Hz, and the decisions are `events` of the nodes `safety`, `power`, `lidar` and `tof`. Scans for localization benchmarks belong next to the SVO recording, not in Forge.

Commands carry the sender's clock: the robot's nodes stamp theirs (`ts`, `source` nav or explore), Forge stamps its own (`source` forge, Mac clock), and HUD commands without a `ts` get the writer's receive time (`source` hud). Both machines run NTP.

## Logs

Every robot node inherits `RabbitNode` (`rabbit/workspaces/rabbit/src/lib/node.py`), which adds `NatsLogHandler` (`lib/log.py`) to the root logger. Each record becomes a JSON message on `rabbit.log.<node>` with the robot wall clock, level, logger, message and template, exception type and traceback, `module:function:line`, the `extra` fields and the node's context (`mission_id` from nav, `map_session` from the camera and explore nodes, `exploration_id` from explore). Identical records (same logger, level, template with numbers ignored and exception) are suppressed for 10 s and the next record carries the suppressed count as `repeats`. The handler also logs uncaught exceptions in the main thread, other threads and the asyncio loop, and a `Node crashed` record before the process exits. The telemetry node logs Docker container events (`docker.events`: started, exited with its exit code, killed, out of memory, health changes), so a segmentation fault inside a native library still leaves a record.

On the robot the `LOGS` JetStream stream (created by `nats/init.sh`: file storage, s2 compression, 7 days, 2 GB) keeps the records while the Wi-Fi is down. The writer reads it with the durable pull consumer `forge-writer` and acknowledges a batch only after ClickHouse stored it. A record belongs to the run that contains its own timestamp, not the run open when it arrived, so a backlog replayed after an outage lands in the right run (`runAt` in `src/runs.ts`).

`logs` is keyed on `(run_id, ts, seq)`, deduplicated on that key when files merge, with a `fingerprint` that groups records of a kind. Word search is `hasAllTokens(lower(message), 'roboclaw error')`: without ClickHouse's text index the tokens are matched as written, so both sides are lower-cased. Retention: info and debug 30 days, warnings and worse 180 days.

- `search_logs` finds records by words (each must appear in the message or the traceback, case-insensitive, also as part of a longer word), node, level and run or time range, grouped by kind with counts, first and last time and the latest traceback.
- `logs_around` lists the records around a moment in time order with their offset in seconds.
- `timeline` returns everything around a moment or a range of at most 15 minutes on one clock: commands with their sender, state transitions (navigation mode, safety faults, missions, exploration phase, camera tracking, Wi-Fi), HUD heartbeat silences, configuration changes, log records (warnings and worse, plus info messages that occur at most three times), and every metric of the graph summarised as moved (min, max, mean, last, sparkline), steady or without data.
- `list_metrics` lists every graph metric with its table, expression and NATS subject, and every table with its subjects.

## Events

`RabbitNode.event(name, reason, severity=..., every_s=..., **fields)` (`lib/node.py`, helpers in `lib/observability.py`) records a decision or a state change. It publishes a JSON message on `rabbit.log.<node>.event`, which the `LOGS` stream keeps like the logs, and also logs a line with `fields['event']` set, so `docker logs` and log search still show it. The writer's log consumer routes `.event` subjects into `events`:

- `name` is `<area>.<what>` in snake_case (`nav.safety_stop`, `planner.plan`, `camera.restart`); `reason` says why in words; `severity` is info, warning, error or critical;
- the ids `mission_id`, `trip_id`, `exploration_id`, `odom_session`, `map_id`, `map_session` come from the node's log context or the call, plus `boot_id` (Linux boot) and `instance_id` (node process); a planner trip carries the exploration that asked for it and a nav mission the trip it belongs to, so one id follows a decision through every node;
- numbers go to `values` and text to `labels`, with the unit in the key (`free_distance_m`, `motor_current_a`, `plan_ms`);
- `suppressed` counts events of the same name and reason skipped by `every_s` since the previous one; a node-wide limit (20/s, burst 100) drops the rest and counts them in `node_metrics.events_dropped`.

Every node also sends `node.start` with a snapshot (code revision and hash, versions, environment, constants), stored in `node_starts`, and `node.stop` with the reason (signal, crash, or the camera's restart reason). `rabbit.metrics.<node>` carries the 10 s process metrics into `node_metrics`. Slabs: `decisions`, `nav_stops`, `camera_restarts`, `node_health`, `node_versions`; `timeline` lists events as decisions and leaves out their duplicate log lines.

Robot containers log through Docker's `json-file` driver with rotation (20 MB, 3 files) set once in `compose.yaml`.

## Slabs

A slab is one reviewed ClickHouse query in `slabs/<id>.yml`:

```yaml
title: Motor current and power by side
description: retrieval text, what the slab answers
tags: [motors, current, power, energy]
prompts: [Which motor drew more current?]
guidelines: how to read the result
dims: [side] # the grain: exactly the axis columns
sql: SELECT ... WHERE run_id = {run_id:String} ...
columns:
  side: { kind: category } # time | ordinal | category | entity | attribute
  avg_current_a: { measure: gauge, unit: A } # gauge | counter | event | ratio
  energy_wh: { measure: event, unit: Wh }
subs:
  min_command:
    { type: Float64, default: 0.1, description: Minimum drive command }
```

A column is a dimension (`kind`) or a metric (`measure`), never both. The measures say how a value may be combined further: a **gauge** is a sampled level (average, min or max; never summed over time), a **counter** is a device's running total (take the difference), an **event** is a count or total that sums, and a **ratio** is recomputed from its parts, never averaged. Time-series slabs take `bucket_s`, where 0 (the default) picks a bucket that keeps the result under about 180 rows. Well-known subs are injected when the SQL references them: `run_id` (default `latest`; `previous` also resolves), `other_run_id` (default `previous`) and the UTC time range `from`/`to` (default the whole run). The loader checks placeholders against `subs`, `dims` against the axis columns, and `forge slab check` asserts each slab's projected columns (via `DESCRIBE`) match its declared columns, then runs it.

| Slab | Answers |
| --- | --- |
| `run_summary` | one-row overview: duration, battery voltage, current, energy, charge, motor current and errors, Jetson peak temperature, path length, tracking drops |
| `drive_tracking` | motor command and nav speed command vs ZED ground speed and motor current over time (stalls) |
| `battery_sag` | battery voltage, current and charge vs motor current over time |
| `battery_resistance`  | linear fit of battery voltage on current: internal resistance, worst unexplained sag |
| `motor_power_by_side` | mean and peak current, power and energy per motor |
| `turn_current` | motor current by steering lock while driving (spikes in full-lock turns) |
| `power_rails` | battery and 6 V rail power and energy |
| `jetson_throttling` | junction temperature, clocks, load, power, share of time below peak clock |
| `power_throttling` | over-current events (OC1/OC2/OC3) per second, share of time throttled, actual vs requested CPU clock, whether jetson_clocks floors were pinned |
| `container_load` | CPU and memory per Jetson container |
| `imu_shocks` | peak deviation from 1 g, RMS vibration, shock count over a threshold |
| `trajectory` | position, step, cumulative distance and speed from the ZED pose |
| `stream_rates` | samples, rate and longest gap per stream (dropouts) |
| `stall_events` | seconds above a motor-current threshold, PWM at the peak, time over threshold, ground speed (stall vs inrush) |
| `brownout_and_gaps` | data gaps with reboot detection (Jetson uptime reset), battery and Wi-Fi state just before |
| `tracking_quality` | camera fps, dropped frames, pose lost share, tracking mode, quality warnings, confidence |
| `steering_response` | steering angle vs IMU yaw rate and ground speed, curvature per unit steer |
| `mission_timeline` | second-by-second nav mode, step, distance and heading error, commands, ground speed, obstacle ahead |
| `power_budget` | battery, motors, Jetson, servo rail and the rest: mean and peak W, Wh, share |
| `thermal_timeline` | Jetson, camera and motor controller temperatures, fan, slowest CPU clock |
| `obstacle_events` | seconds with an obstacle closer than a clearance, nav mode and speed at that moment |
| `run_compare` | two runs side by side (`run_id`, `other_run_id` default latest and previous) |
| `wifi_health` | signal, router ping p50/p95/max, lost pings, throughput, drops |
| `obstacle_clearance`  | nearest obstacle overall and ahead, close calls under a clearance |
| `nav_missions` | per mission or goal: plan, arrived, cancelled or replaced, time to arrive, share of time blocked |
| `planner_trips` | route planner trips (go_to, HUD GO TO, exploration legs): target, start and end, final phase and message, replan reason, route length, replans, recoveries |
| `explorations` | explorations: start and end, final phase and why they ended, distance driven, frontiers, limits |
| `nav_transitions` | navigation mode, safety fault and mission changes with the speed command and free distance at that moment |
| `command_timeline` | per bucket: gamepad, navigation drive commands, stops, goals, missions, cancels and other commands with their sender, HUD heartbeats |
| `operator_link` | HUD heartbeats per second, round trip p50 and max, longest silence |
| `log_summary` | log records per node and level: count with repeats, kinds, most frequent message, latest exception, first and last time |
| `log_error_rate` | warnings and errors per second per node over time, with the most frequent message |
| `container_events` | robot container starts, exits with exit code, kills, restarts, out-of-memory and health changes |
| `decisions` | every recorded event in order with reason, ids and measured values; `id` follows one mission, trip or exploration through every node |
| `nav_stops` | why the robot stopped or did not move: safety stops, holds, cancels and their sender, overrides, rejections, motor command timeouts, failed trips |
| `body_safety` | Rabbit 2.0 safety loop per second: worst mode, limiting reasons, requested vs allowed speed, clearances, E-stop line, bumpers, safety events |
| `camera_restarts` | per boot: camera restarts and their reasons, relocalizations and their time, failures, map archives, resets and saves, node crashes |
| `node_health` | per node: CPU mean and peak, peak and last RSS, worst event-loop stall, NATS traffic, error and drop counters, restarts |
| `node_versions` | every node start with git revision, source hash, Python and environment, and the value of one constant (`key`) |

`search_slabs` is deterministic BM25 (MiniSearch) over id, title, description, tags, prompts and column names.

## Metric graph

`graph/metrics.yml` is a typed graph of the robot's metrics: 56 nodes and 85 edges. A node is a measured series (`source: {table, expr, agg}` binned in ClickHouse, with unit, native rate `hz` and sensor resolution `floor`; `agg: rate` counts rows per second, with empty bins as zero, for logs and heartbeats) or an event list read from a slab (`events: {slab, time, end, where}`: reboots and data gaps from `brownout_and_gaps`, stalls from `stall_events`, navigation safety stops from `nav_transitions`, container crashes from `container_events`, missions from `nav_missions`); every node names the slabs that fetch it. Commands connect to what they move (gamepad throttle and the navigation speed command to the motor command, then PWM, current and ground speed; gamepad and navigation steering to the steering angle; missions to the navigation speed), safety stops to the signals behind each rule (motor current and ground speed for a stall, an IMU jolt for a collision, free distance for blocked, HUD heartbeats for operator link lost, the gamepad for a manual override) and to the navigation logs, and the log rates per node decompose the total. An edge is directed and typed, with a reason (`why`), an evidence class (`physics`, `design`, `observed`) and an optional `sign`:

| Relation | Direction | Example |
| --- | --- | --- |
| `decomposes_into` | total to part | battery_power into motor, Jetson, servo power |
| `drives` | cause to effect  | battery_current to battery_voltage (negative) |
| `causes` | cause to effect  | junction_temp to cpu_freq (negative) |
| `explains` | load to level | drive_command to motor_current |
| `correlates_with` | none | cpu_temp with junction_temp |
| `guards` | safety to action | obstacle_clearance to nav_blocked |
| `symptom_of` | event to cause | reboots to battery_voltage, imu_vibration |

The loader validates the file like slabs: node ids, units and rates for series, known slabs, slab columns for event nodes, known edge ends, no self loops or repeated edges. `pnpm forge graph check` runs every series expression against the latest run.

- `metric_graph` (tool, `pnpm forge graph [<metric>]`) returns a node's neighbourhood (`hops`), the shortest path between two metrics (`node`, `to`) or the whole graph, optionally filtered by relation.
- `investigate` (tool, `pnpm forge investigate <metric>`) walks upstream from a symptom breadth-first (decompositions only as the first hop, at most 14 nodes, depth 2 by default), fetches every candidate on one grid (10 Hz up to 15 minutes, else 1 Hz) and compares each with its trailing 30 s median (robust z). For an event (`at` picks the nearest one, and the run containing it when `run_id` is omitted) the focus is the 15 s before it; for a metric it is the strongest deviation in the range (or the one nearest `at`). A link scores on how far the cause deviates in the focus window in the expected direction, its cross-correlation with the effect within 3 s of lag and whether it leads; a chain scores the blend of its geometric mean and its weakest link. It returns ranked hypotheses with evidence, a breakdown into parts, what it ruled out (link score below 0.15), the metrics without data, and `context`: the commands, state transitions and log records from 20 s before the focus to 5 s after it.

Both return `{kind: 'graph', id, title, nodes, edges, highlights}`; nodes carry role, status, value at the peak and a sparkline, edges their score and lag, `highlights` the top chain, and `investigate` adds a stacked chart of the chain. The HUD draws it as a node-link diagram.

On today's data: the 11:00:17 reboot ranks the uncommanded 0.429 A motor current and the 0.148 g IMU jolt 3 s before the gap first (0.85 each) and rules out Jetson power and heat; the 10:48 reboot finds no precursor (top chain 0.11, battery ruled out); the 11:04:12 stall is the 0.3 command step (12.6 A inrush); the 11:33:53 current rise is the navigation command with the corridor 0.16 m ahead; the Wi-Fi ping peak is 619 ms at 11:32:15.

## Anomaly detection

`detect_anomalies` (MCP tool, `ask` tool, `pnpm forge detect <signal>[,<signal>...]`) scores one to four graph metrics at once over a run against a forecast from `amazon/chronos-2` on tsfm.ai. The signals go in as one multivariate target (Chronos-2 takes `target` as `[time][channel]`, `null` for gaps), with past and future covariates picked from the graph: the metrics with an `explains` or `drives` edge into a target, by evidence class, at most four (`covariates` overrides them, `[]` forecasts from history alone). `NX-AI/TiRex-2` is the fallback, one channel per input, then the reference alone. Renamed signals: `camera_fps` is `zed_fps`, `jetson_cpu_temp` is `cpu_temp`, `jetson_cpu_freq` is `cpu_freq`.

ClickHouse resamples to bin means (10 Hz with context up to 512 and horizon 16 when the range is at most 15 minutes and every target is sampled at 10 Hz or faster; otherwise 1 Hz with 256 and 30). Windows need 64 points of history and at least half of it observed for some target, so a signal that starts late is still scored. Then, per signal:

- **Calibration.** Thresholds come from the signal's clean windows (all but the 5 % with the largest exceedance): a point is flagged above the 99.8th percentile of clean band exceedance (at least `threshold` band widths outside the 5-95 % band), a stretch when its 10-point mean deviation (each point clipped at 3) exceeds the clean 99.8th percentile.
- **Reference.** A run-wide reference (median and robust spread of the signal at the same levels of its two main covariates, per quarter of the range) flags regime shifts the forecast absorbs into its own context, such as a robot pushing a wall for 15 s: 10 points whose median deviation exceeds the clean 99.8th percentile (at least 6 sigma). Each event reports `reference_z` and `reference_agrees`.
- **Severity.** The event's peak over its threshold: alert from 4, warn from 2, info below. A short event that starts with a step in an explaining covariate (a command starting) is marked `at_covariate_step` and judged on an eight times wider margin, so start-up inrush stays visible only when it is extreme.
- **Joint events.** Events of different signals within 2 s (5 s at 1 Hz) form a joint event that names the signal that moved first.

The chart is stacked, one panel per signal with the observed line, the dashed expected median, the forecast band and the event ranges. Gaps are never scored; reboots and dropouts come from `investigate` or `brownout_and_gaps`.

`pnpm forge eval tools` checks `investigate` and `detect_anomalies` against labels verified in the raw data (`evals/tools.yml`): the 11:04:12 inrush, the 11:00:14 knock before the reboot (motor current and IMU), both wall pushes (11:33:53 and 11:34:46), the two Wi-Fi ping episodes (11:31:52 to 11:32:26 up to 619 ms, 11:33:51 to 11:34:03 up to 278 ms), the 11:37:08 uplink drop and the 0.43 V battery step at 10:05:27 with no current change. Counting warn and alert events, all 9 labelled events are found (recall 1.0) at a precision of 0.55 to 0.6 between runs; most remaining false alarms are real but unlabelled deviations (sub-amp current spikes while driving, single-sample uplink dips). The first multivariate version, forecast only, found 4 of 6 events at a precision of 0.4. All 11 cases pass.

## SQL gate

Every ad-hoc or generated query passes `src/sql/validate_sql.ts` (parsed with `@polyglot-sql/sdk`) and then `EXPLAIN PLAN` in a read-only reader session:

- exactly one `SELECT` / `WITH` / `UNION` statement;
- only Forge tables, CTEs of the query and subqueries; no other database, table function, `FINAL` or `SETTINGS` (table functions matter more now: the engine can read any file the process can, so the gate is what keeps the agent's SQL on the Forge views);
- no `FORMAT`, `INTO OUTFILE`, `GLOBAL IN` or references to `system` / `information_schema`;
- functions come from an allowlist (aggregates and their combinators, window, math, date and time, string, array, JSON and conditional functions), including those named in `* APPLY(fn)`, so anything reading server state or other data is rejected;
- every `JOIN` matches qualified `run_id` columns of its two sides with AND only (no `OR`), plus a time or sequence key from both sides (a shared bucket, or `ASOF ... a.ts >= b.ts`) unless one side is aggregated to one row per run; no comma joins. Two runs never pair up, and no join multiplies every row of a run with every other.

A test runs every slab through the gate, so a rule that is too strict fails CI rather than a slab.

A rejection returns a stable error plus a repair hint for the model (the columns of the tables it read, the GROUP BY rule, the aggregate-alias trap), as Nexus does with `NexusError.llm`.

## Agent

`ask` (CLI and MCP tool) starts with the recent runs and the five nearest slabs in context, and can call `list_runs`, `search_slabs`, `run_slab`, `write_query`, `detect_anomalies`, `metric_graph`, `investigate`, `timeline`, `search_logs` and `logs_around`. It runs a slab when one covers the question (fast path); otherwise it calls `write_query`, a sub-agent that sees the schema and the three nearest slabs' SQL and must commit through `finalize`, which runs the gate and EXPLAIN and returns repair hints until the SQL is valid (heavy path). The answer cites the run and the slab or SQL, and every number must come from a tool result. Data and tool parameters are UTC; the operator works in `config.operatorTimeZone` (Australia/Sydney), whose current time and offset the agent receives with every question, so it converts the operator's times for tools. Times in tool results reach the model twice: as UTC and as a `<field>_local` twin already in Sydney time with its abbreviation (`src/local_time.ts`, the IANA zone, so AEDT from 2026-10-04 02:00 is right), plus a `timezone` note; the prompt has it quote those and never do offset arithmetic, after the evals caught it adding 11 h in AEST. The result reports `path: fast | heavy` and a trace of tool calls.

## Chat API

The `forge-chat` service runs on the robot behind `rabbit-web` (nginx), which serves the HUD at `https://jetson.rabbit` and proxies `/api/` to the chat with `Host: localhost:18080`, passing the browser's `Origin` and filling it in for same-origin requests (browsers omit it on same-origin GETs). The HUD reads the base URL from `VITE_CHAT_URL` in `workspaces/web/src/chat/session.ts`: the robot build sets it empty (same origin), and the dev server on the Mac defaults to `https://jetson.rabbit`. `pnpm forge serve` runs the same server on a laptop at `http://127.0.0.1:18080` for development.

- `POST /api/chat` takes `{ messages: UIMessage[] }` (stateless, the client sends the history; only `user` and `assistant` messages) and streams the AI SDK UI message stream. A client that disconnects aborts the agent run. It requires an allowed `Origin` (`https://localhost:*`, `https://dev.rabbit:*`, `https://jetson.rabbit`) and `content-type: application/json`. There is no token: the chat is only reachable on the robot's local network, and the origin check keeps other websites from driving it.
- Only the `Host` values `127.0.0.1:18080` and `localhost:18080` are served (nginx sets the latter), which blocks DNS rebinding.
- `GET /api/health` returns `{ ok, model, clickhouse, latest_data_age_s, run }`; `clickhouse` says whether the embedded engine answers.

The chat agent is `ask` with more tools: the data tools, `write_query`, `chart` (plots a slab or SQL result; the server converts times to epoch ms and downsamples to 2000 rows), and the robot tools `robot_status`, `go_to`, `plan_route`, `find_object`, `list_places`, `save_place`, `run_mission`, `stop`, `save_map`, `start_run` and `stop_run`. `go_to` (approval) and `plan_route` (preview, no motion) resolve the destination in Forge and hand it to the robot's route planner (`rabbit.planner.goal`, request-reply): an object name (aliases such as fridge map to detector classes) is looked up in `objects` since the last map archive or reset (taken from rabbit-zed's logs), detections made while rabbit-zed is still relocalizing (INITIALIZING/SEARCHING, a temporary frame) are dropped, sightings are clustered within 0.8 m and the most-seen cluster wins, and the camera positions it was seen from (pose ASOF-joined to the detections) go along as `seen_from` so the planner prefers viewpoints with a proven line of sight; a room (kitchen, bedroom, ...) resolves to a saved place of that name or else to its typical objects; `x`/`z` is a point. The planner picks a viewpoint facing the object, plans on the map and drives the route through nav, replanning on its own; the tool waits up to 6 s for the plan and returns the route, or fails with the planner's reason. `save_place`/`list_places` keep named places on the robot (`rabbit.planner.places*`), per map. `run_mission` publishes `rabbit.nav.mission {id, steps}` (turn, move, goto, queued on the robot) and needs the operator's approval: tools declare `requiresApproval`, chat turns that into AI SDK tool approval signed per server process, and execution consumes a single-use approval that expires after 2 minutes (MCP never registers such tools). Before publishing, the server re-checks that the pose, camera tracking and obstacle readings are fresher than 3 s, tracking is OK and the first leg that moves is clear of the obstacle ahead (when it starts within 10 degrees of the current heading), and enforces at most 3 m per move, 5 m per goto, 10 steps and 10 m per mission, dead-reckoning the steps so each goto is measured from where the earlier steps leave the robot. The mission carries its own `id` (`forge-<uuid>`); the tool waits up to 3 s for `rabbit.nav.state` to report that `mission_id` (`accepted`), fails with nav's reason when nav sets a new `rejected: ...` fault, and otherwise returns `accepted: false`. `nav_state.mission_id` keeps the last mission after it ends, so whether a mission is running comes from `mode`. `stop` publishes `rabbit.nav.cancel` and a zero `rabbit.cmd.drive` independently, without approval, and reports each; the robot NATS connection reconnects indefinitely and every publish waits at most 3 s for the server. Chat never publishes a non-zero drive command. Tools return `{kind: 'table'}`, `{kind: 'chart'}` (optional `layout: 'stacked'`, `series.panel` and `dashed`, range markers with `x_end` and `series`, bands per series, and an `id`), `{kind: 'graph'}` or `{kind: 'status'}`; the model sees a summary of charts and graphs instead of their rows. The chat prompt asks for a TL;DR, key numbers, findings with status chips and evidence, and next steps, written with inline tokens the HUD renders: `ok:`, `info:`, `warn:`, `alert:` (status chips), `kpi:Label=value` (key numbers), `spark:v1,v2,...` (sparklines), `ref:kind:target?key=value` (evidence chips that re-run a slab, detection or investigation, or scroll to a chart or graph by id) and `next:question` (follow-ups).

## MCP

```sh
claude mcp add forge -- node /Users/sergey/projects/rabbit/workspaces/forge/src/cli.ts mcp
```

Tools: `list_runs`, `search_slabs`, `run_slab`, `query`, `describe_schema`, `detect_anomalies`, `metric_graph`, `investigate`, `timeline`, `search_logs`, `logs_around`, `list_metrics`, `ask` (no robot actions over MCP). All are read-only. To try it without Claude Code:

```sh
npx @modelcontextprotocol/inspector --cli node src/cli.ts mcp --method tools/list
```

## Development

```sh
pnpm check    # oxfmt --check, tsc, oxlint (type-aware), vitest
```

Tests cover the Parquet store (every view has exactly the schema's types; enums, maps, nullable arrays and computed columns survive a round trip; an uncommitted file is never read and is cleaned up; a retried write replaces its own file; merge inputs a crash left behind are removed; compaction, deduplication and log retention; every slab passes the gate and EXPLAIN on the views), the SQL gate, the writer's batching (bisection, retries, the buffer cap), mission planning and acceptance, approvals, slab search ranking for Russian and English questions, the metric graph loader and traversal, the graph statistics, grid filling (gaps and zero-filled rates), joint events, the anomaly reference, the run a record belongs to by its timestamp, and the mapping of robot log records to rows. The robot's log handler (repeat suppression, payload fields) is tested in `rabbit/workspaces/rabbit/tests/test_log.py`.

`pnpm forge eval [<case>]` runs the chat agent on `evals/chat.yml` (questions with the tool calls, approvals and facts each answer must contain) against the store in `FORGE_DATA_DIR` and the model, with robot actions as dry runs and a fixed `robot_status` (`heading_deg` and `obstacle_ahead_m` set its pose and obstacle). Cases do not name fixed runs or times: `anchor` is SQL run on the store first, and its first row fills `{column}` placeholders in the question, facts and approval input (the longest run, the biggest motor-current peak, the longest data gap, the latest camera restart, relocalization, operator stop, exploration and refrigerator trip, a rarely seen object, an object only in an earlier map); times in facts accept both UTC and Sydney time. A case whose anchor finds nothing is reported as skipped, not failed. `history` puts earlier messages before the question, which covers approval cards left unanswered and approvals that expired. 38 cases.
`pnpm forge eval tools` is the deterministic check for `investigate` and `detect_anomalies` (see Anomaly detection). Schema changes need no migration: edit `src/store/schema.sql` and restart.

## Data notes

- `roboclaw.supply_voltage` is the 12 V buck output feeding the motor controller, not the battery; battery voltage and power come from `power`.
- Motor current is measured at 12 V by the RoboClaw; battery current is measured at the pack and includes the Jetson, camera and servos.
- `rabbit.health.zed` occasionally publishes invalid JSON (NaN values); the writer counts and drops those messages.
- Wi-Fi telemetry starts at about 11:30 on 2026-10-01, so the earlier 1.5 s ping episode has no Wi-Fi rows.
- `battery_charge_pct` is a voltage-curve estimate and reads low under load. Rows recorded before the robot published it are NULL.
- Currents from `power` saturate at the INA's ±81.92 mV shunt range: 8.19 A on the 10 mOhm shunts. From 2026-10-03 `battery_clipped` and `rail_6v_clipped` are true from 90% of that range (7.37 A), so a peak such as the 7.64 A of 1 Oct is a lower bound, not the true peak; older rows are NULL. Each INA start records the shunt, current LSB and SHUNT_CAL of every channel in `events` (`power.calibrated`); before 2026-10-03 every channel was calibrated for 10 mOhm, so a channel with another shunt was scaled by R_true / 0.01.
- `roboclaw.duty_max` is the voltage cap rabbit-roboclaw applies (`pwm` = command × `duty_max` after the slew): 1 while the RoboClaw is on the 12 V buck, 12 / V on the 4S pack.
- `magnetometer.heading_deg` is meaningless while `heading_state` is `NOT_CALIBRATED`.
- Right after the ZED node restarted at 10:46, about 5 minutes of `pose` and `obstacle` rows carry camera timestamps up to 5.7 minutes behind the robot clock; later rows are aligned.
- The wheel encoders are not connected, so `roboclaw` speed and encoder columns are always 0; ground speed comes from `pose` velocity.

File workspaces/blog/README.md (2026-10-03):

```yaml
id: 1
date: 18-05-2025
```

Decided to dust off my soldering skills a bit and mix that with what I’ve learned working as a full-stack dev. I want to build a robot that can be controlled over the internet and uses [Ackermann steering](https://en.wikipedia.org/wiki/Ackermann_steering_geometry). The second step is to dive deeper into [ROS2](https://github.com/ros2/ros2) and autonomous navigation.

---

```yaml
id: 2
date: 18-05-2025
media:
  - 1-1.jpg
```

Ordered some basic components and tools for assembly from AliExpress and Amazon.

---

```yaml
id: 3
date: 18-05-2025
```

I was planning to run the steering servo today and try to turn it with the [Raspberry Pi](https://www.raspberrypi.org/), but Amazon didn't deliver the solder so I'll have to wait to do any soldering.

---

```yaml
id: 4
date: 18-05-2025
```

Turns out Raspberry Pi has just one PWM output, which is OK for tests but I still ordered the [16-channel PWM driver PCA9685](https://www.adafruit.com/product/815) just in case I decide to add another servo. Better to overdo it than hack together some ugly workaround later.

---

```yaml
id: 5
date: 18-05-2025
```

I found out there are 2 ways to work with [DualSense](https://www.playstation.com/en-us/accessories/dualsense-wireless-controller/) from the browser: [Gamepad API](https://developer.mozilla.org/en-US/docs/Web/API/Gamepad_API) (standard but limited) and [WebHID API](https://developer.mozilla.org/en-US/docs/Web/API/WebHID_API) (full access to all features).

---

```yaml
id: 6
date: 21-05-2025
```

[RoboClaw](https://www.basicmicro.com/RoboClaw-2x30A-Motor-Controller_p_9.html) doesn't stop if your script crashes - that's dangerous! You definitely need to enable RC timeout and send commands in a loop.

---

```yaml
id: 7
date: 22-05-2025
media:
  - 7-1.mp4
```

Finally got the motors running via [UART](https://ru.wikipedia.org/wiki/UART)! First sign of life.

---

```yaml
id: 8
date: 22-05-2025
```

The problem was that I stupidly bought a [TXB0104](https://www.ti.com/product/TXB0104), thinking that this level shifter would work with UART and let me connect RX on the RoboClaw (which runs at 5V), but it didn't work. I disconnected it and just left TX 3.3V from the Raspberry Pi.

---

```yaml
id: 9
date: 22-05-2025
```

In the end I'll order a [TXS0108E](https://www.ti.com/product/TXS0108E) or just quickly throw together a voltage divider on resistors but I need to go to [Jaycar](https://www.jaycar.com.au/) for resistors.

---

```yaml
id: 10
date: 22-05-2025
```

For now everything is of course held together with wires and mounted on a breadboard – I probably need to solder all this onto a proper PCB with real traces instead of wires. But first I need to make it actually move. One step at a time!

---

```yaml
id: 11
date: 22-05-2025
media:
  - 11-1.mp4
```

The servo works too but I'm waiting for a quieter and more precise [brushless servo](https://www.aliexpress.com/w/wholesale-brushless-servo.html) from AliExpress. Once it arrives I'll swap it.

---

```yaml
id: 12
date: 24-05-2025
```

Started thinking about a custom PCB and dusting off the laser iron. Spent some time with [KiCad](https://www.kicad.org/) and realized it's too early - there are still too many things I don't understand. I'll put it off until [MCP](https://modelcontextprotocol.io/) comes out for PCB-CAD or I finally figure things out. Maybe one day Claude will learn to design boards.

---

```yaml
id: 13
date: 24-05-2025
```

For now I'm thinking to stick with the prototype board and put everything together on it. At least the layout will be clear and it'll be a bit easier to spread everything out later.

---

```yaml
id: 14
date: 24-05-2025
media:
  - 14-1.jpg
```

Today was actually pretty good progress. I bought 3 prototype boards and connected them together.

---

```yaml
id: 15
date: 25-05-2025
media:
  - 15-1.mp4
```

I'll talk about this a bit later, but turns out I forgot to increase the current limit on the power supply when I tested the robot for the first time. So, when testing the joystick, if I suddenly pressed the trigger, the current jumped and the rpi would shut down. After sitting down with the logs for a while, I found this:

```
May 25 01:36:39 rabbit kernel: hwmon hwmon2: Undervoltage detected!
May 25 01:36:41 rabbit kernel: hwmon hwmon2: Voltage normalised
```

which shows there's a problem. I'll try to raise the max to 3 - 4 A and see how it goes.

---

```yaml
id: 16
date: 25-05-2025
media:
  - 16-1.jpg
  - 16-2.jpg
  - 16-3.jpg
```

Going back to the board. I got really lucky ordering nylon standoffs from Amazon. First, I fixed the steering mechanism by making the arms a bit longer. Second, these standoffs make it super easy to place all the PCBs on the prototyping board.

---

```yaml
id: 17
date: 25-05-2025
media:
  - 17-1.jpg
```

I took apart the rpi, removed the heating sink, but stuck on some heat sinks

---

```yaml
id: 18
date: 25-05-2025
media:
  - 18-1.jpg
```

Had to make the holes for M3 a bit bigger

---

```yaml
id: 19
date: 25-05-2025
media:
  - 19-1.jpg
  - 19-2.jpg
```

Soldered a common GND for all elements using dupont pins

---

```yaml
id: 20
date: 25-05-2025
media:
  - 20-1.mp4
```

I added an LM2596 for the servo and set it to 6V like my dad suggested. I need to order a few more of these but with a screen so it's easier to monitor the voltage without a multimeter.

---

```yaml
id: 21
date: 25-05-2025
media:
  - 21-1.jpg
```

Before that I also soldered a voltage divider to connect the RX of the rpi and roboclaw because they work at different levels: 3V and 5V. But I've already swapped it for a step-down converter.

---

```yaml
id: 22
date: 25-05-2025
media:
  - 22-1.jpg
```

At first I thought about powering the rpi directly from gpio 2 or 4 but decided not to do it so I don't fry it by accident. In the end I took a step-down regulator polou 5V D24V90F5 and soldered a usbc cable to connect them. Maybe this could also be done a bit neater.

---

```yaml
id: 23
date: 25-05-2025
media:
  - 23-1.mp4
```

The first launch didn't go so well because one wire was soldered badly and I spent a long time looking for the problem but after checking with a multimeter I found the issue and everything started working.

---

```yaml
id: 24
date: 25-05-2025
media:
  - 24-1.jpg
  - 24-2.jpg
```

Resistors for the 5V -> 3.3V divider. Had to remember Ohm's law 🤔

---

```yaml
id: 25
date: 25-05-2025
```

It's actually interesting to remember everything I went through at school, university and heard from my dad and use it in the real world.

---

```yaml
id: 26
date: 25-05-2025
```

For now, I decided not to bother with bluetooth for controlling it through the PS5 dualsense, especially since the final goal is control over the internet, not bluetooth.

---

```yaml
id: 27
date: 25-05-2025
```

Connecting the controller turned out to be easy and everything worked the first time. I’m thinking of making the R2 trigger control forward movement. The value range from 0 to 255 can be normalized to roboclaw’s range (-32767, 32767) with a simple formula.

---

```yaml
id: 28
date: 25-05-2025
```
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

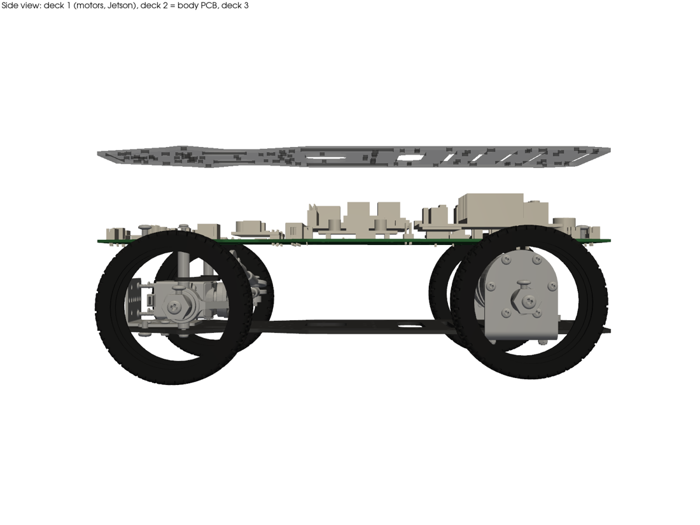
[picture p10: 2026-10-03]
docs/reports/media/body-pcb-chassis_side.png

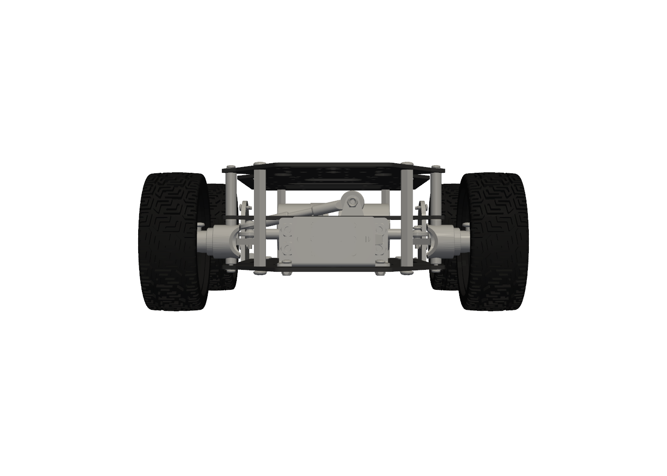
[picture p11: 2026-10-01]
model/renders/chassis_front.png

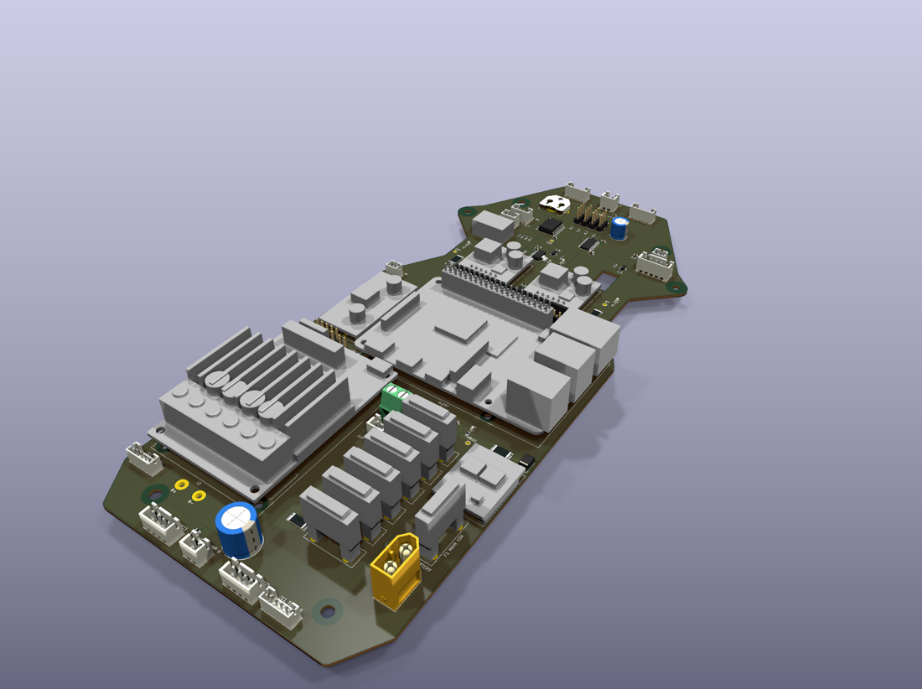
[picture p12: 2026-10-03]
docs/reports/media/body-pcb-iso.png

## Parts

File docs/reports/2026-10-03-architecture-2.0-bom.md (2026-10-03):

# Rabbit 2.0: покупки (BOM)

Приложение к [`2026-10-03-architecture-2.0.md`](2026-10-03-architecture-2.0.md). Выводы и проводка — в [`-wiring.md`](2026-10-03-architecture-2.0-wiring.md).

**Как читать цены:**
- цены проверены 2026-10-03 на страницах производителей и магазинов (ссылки ниже);
- AUD — Core Electronics с GST;
- **«оценка»** — цену проверить не удалось: курс ~1,5 AUD за USD или типичная цена категории;
- **Есть** — уже у владельца.

## Что уже есть

| Позиция | Роль в 2.0 |
|---|---|
| Jetson Orin Nano Super 8 GB dev kit, NVMe 915 ГБ | мозг |
| ZED 2i | камера |
| NEEWER PS099E + площадка V-mount | батарея |
| RoboClaw 2x30A | моторы, энкодеры |
| 2× Pololu 37D 70:1 12 В с энкодерами 64 CPR (#4754) | привод |
| AGFRC A50BHL + Adafruit PCA9685 | руль |
| TI INA4235EVM | монитор питания; заменить шунты, см. `-wiring.md` |
| Pololu D36V50F12 ×2 | один — Jetson; второй освобождается, когда RoboClaw переходит на батарею |
| Pololu D36V50F6 | серва |
| Pololu D24V90F5 (5 В 9 А, вход 5–38 В) | **5 В для Pi**: вместо покупки D24V50F5 |
| Pololu D24V22F12 | резерв (был для TRB246) |
| Raspberry Pi 4 (с мая 2025) | тело; **проверить, что 8 ГБ** |
| Adafruit TCA9548A, Teltonika TRB246, Evemodel блок, XY-CD63L | резерв / отложено |

## Купить

| # | Позиция | Почему эта | Цена | Ссылка |
|---|---|---|---|---|
| 1 | **Лидар Slamtec RPLIDAR C1** | дешевле и точнее LD19: ±30 мм против ±45 мм, 0,72° против ~1°, 6 м по чёрному, IP54. LD19 (Waveshare D300) снят с производства. 0,05–12 м, 10 Гц, 5000 точек/с, UART 3,3 В 460800, 5 В (0,8 А старт / 0,26 А работа), 110 г, Ø55,6 мм | **A$129,95** (в наличии), US$69 | [Core](https://core-electronics.com.au/rplidar-c1-dtof-lidar-360-laser-range-scanner-12m-ip54.html), [DFRobot](https://www.dfrobot.com/product-2803.html), [даташит](https://files.waveshare.com/wiki/RPLIDAR-C1/SLAMTEC_rplidar_datasheet_C1_v1.0_en.pdf) |
| 2 | **4× VL53L8CX на Pololu #3419** | при 5 клк видит в 1,4–1,7 раза дальше, чем VL53L5CX (окна), на 30% экономнее; регуляторы и сдвиг уровней на плате. 8×8 при 15 Гц, 45°×45°, 2–400 см | 4 × A$41,05 = **A$164,20**; US$24,95 шт. | [Core](https://core-electronics.com.au/vl53l8cx-time-of-flight-88-zone-distance-sensor-carrier-with-voltage-regulators-400cm-max.html), [Pololu](https://www.pololu.com/product/3419), [даташит](https://www.farnell.com/datasheets/3930859.pdf) |
| 3 | Регулятор 3,3 В ~1 А с EN для ToF (например, Pololu D24V10F3) | ToF питаются от 3,3 В, не от 3V3 Pi | ~A$12 (оценка) | pololu.com |
| 4 | 6× микропереключатель Omron D2F-01L (4 + 2 запасных) | «01» — для слабых логических токов, нормально замкнутый контакт, 0,78 Н | US$1,44 шт., ~A$15 (оценка) | [DigiKey](https://www.digikey.com/en/products/result?keywords=D2F-01L), [даташит](https://omronfs.omron.com/en_US/ecb/products/pdf/en-d2f.pdf) |
| 5 | **Выключатель Pololu Big Pushbutton HP #2813** | единственный у Pololu ~15 А: 4,5–32 В, 6 А длительно / 16 А тепловой предел, вход OFF ≥ 1 В, ток в выключенном < 0,2 мкА | **A$12,20**, US$8,95 | [Core](https://core-electronics.com.au/big-pushbutton-power-switch-with-reverse-voltage-protection-hp.html), [Pololu](https://www.pololu.com/product/2813) |
| 6 | Кнопка двухполюсная (2NO) без фиксации, 16–19 мм, подсветка 5 В | полюс 1 включает, полюс 2 сообщает Pi | ~A$15 (оценка) | — |
| 7 | TVS SMBJ20A | на выход выключателя (рекомендация Pololu) | ~A$1 (оценка) | — |
| 8 | Блок предохранителей Blue Sea 5025 (6 × ATO, отрицательная шина, крышка) | звезда земли и предохранители в одном месте; 30 А на цепь | US$46,95, ~A$70 (оценка); дешёвый аналог 6×ATO ~A$20 (оценка) | [Blue Sea](https://www.bluesea.com/products/5025/ST_Blade_Fuse_Block_-_6_Circuits_with_Negative_Bus_and_Cover) |
| 9 | Держатель предохранителя ATO в разрыв провода (главный 15 А) | | A$4,30 | [Core](https://core-electronics.com.au/standard-duty-30a-blade-fuse-holder.html) |
| 10 | Предохранители ATO 15, 10, 7,5, 5, 5, 2 А + запас | | ~A$10 (оценка) | — |
| 11 | Шунты 2512 ≥ 1 Вт: 2 мОм и 5 мОм, по 2 шт. (Ohmite PCS2512 или аналог) | каналы 1 и 3 INA, см. `-wiring.md` | ~A$10 (оценка) | — |
| 12 | Конденсатор Panasonic EEU-FR1V102, 1000 мкФ 35 В, 18 мОм | на клеммы RoboClaw | ~US$1–1,7 | [DigiKey](https://www.digikey.com/en/products/detail/panasonic-industry/EEU-FR1V102/2433579) |
| 13 | XT60 пара | от площадки V-mount | A$4,40 | [Core](https://core-electronics.com.au/xt60-connectors-male-female-pair.html) |
| 14 | Силиконовый провод AWG14/16/18/20/22/26, наконечники, термоусадка, JST-XH | | ~A$40 (оценка) | — |
| 15 | 3× MOSFET 2N7000/BSS138, резисторы 1k/4,7k/10k/100k/330, 100 нФ | Q1–Q3, подтяжки | ~A$5 (оценка) | — |
| 16 | RTC Adafruit DS3231 #3013 + CR1220 | время Pi и всей системы без интернета | A$29,95 + ~A$3; US$17,50 | [Core](https://core-electronics.com.au/adafruit-ds3231-precision-rtc-breakout.html), [Adafruit](https://www.adafruit.com/product/3013) |
| 17 | **Raspberry Pi Flash Drive 256 ГБ** (USB 3, UAS, SMART, 22 тыс. IOPS случайной записи) | загрузка и данные; у Samsung T7 известна проблема с загрузкой на Pi 4 (firmware#1799) | **A$109,95**, US$55 | [Core](https://core-electronics.com.au/raspberry-pi-256gb-flash-drive.html), [Raspberry Pi](https://www.raspberrypi.com/products/flash-drive/) |
| 18 | USB-хаб Waveshare USB3.2-Gen1-HUB-4U (металл, клеммы 7–36 В, 2 А на порт) | питание прямо от батареи (F5), не грузит 5 В Pi | US$17,99, ~A$27 (оценка) | [Waveshare](https://www.waveshare.com/usb3.2-gen1-hub-4u.htm); альтернатива — [хаб Raspberry Pi](https://core-electronics.com.au/raspberry-pi-usb-3-0-hub.html) A$21,29 (5 В через USB-C) |
| 19 | **Wi-Fi Alfa AWUS036ACM** (MT7612U, драйвер в ядре с 4.19, 2× RP-SMA 5 дБи, ~380 мА) + USB-удлинитель | зрелый драйвер. У AXML (MT7921) открыта ошибка mt76#1141 на Pi 4 с ядром 6.18 | US$37–47, ~A$65 (оценка) | [morrownr](https://github.com/morrownr/USB-WiFi/blob/main/home/USB_WiFi_Adapters_that_are_supported_with_Linux_in-kernel_drivers.md) |
| 20 | Camera Module 3 Wide (IMX708, 120° по диагонали, 102° по горизонтали, автофокус) + шлейф 300 мм Adafruit #1648 | задняя камера; владелец купит | US$38,50 + US$1,95, ~A$62 (оценка; на Core цена не проверена) | [PiShop](https://www.pishop.us/product/raspberry-pi-camera-module-3-wide/), [Adafruit](https://www.adafruit.com/product/1648) |
| 21 | Cat6 0,5 м | Jetson ↔ Pi | A$4,10 | [Core](https://core-electronics.com.au/cat6-05m-patch-cable-rj45.html) |
| 22 | Охлаждение Pi: 52Pi ICE Tower (вентилятор от 5 В) | Pi внутри корпуса робота под нагрузкой Forge и видео | US$12,48–22, ~A$30 (оценка) | [52Pi](https://52pi.com/collections/ice-tower-cooler-1) |

**Итого купить: ~A$825** (~US$550 по курсу 1,5). Из них ~A$460 — проверенные цены, остальное оценки.

**Если Pi 4 не 8 ГБ:**
- Pi 4 8 ГБ сейчас стоит **A$267,63 / US$165** (подорожание 2025–26 из-за памяти) — итого ~A$1 090;
- 4 ГБ, скорее всего, хватит: Forge ~0,3–1 ГБ, NATS, nginx, узлы тела ~0,5 ГБ.

**Где сэкономить:**

| Замена | Экономия |
|---|---|
| VL53L5CX на Pololu #3417 (A$33,75) | −A$29; хуже на свету, есть Python-драйвер Pimoroni |
| дешёвый блок предохранителей | ~−A$50 |
| хаб Raspberry Pi вместо Waveshare | ~−A$6 |

**Необязательное:**
- Батарейка RTC для Jetson: на dev kit разъём J3 и резистор R560 **не распаяны**. Нужны Molex PicoBlade 53398-0271, резистор 0402 и CR1225 с выводом PicoBlade 51021 (~A$10, оценка, плюс пайка SMD). Предлагается не делать: время Jetson берёт с Pi.
- Изолятор USB (ADuM3160) для USB RoboClaw — если USB останется основным каналом (~A$30, оценка).

## Источники характеристик

- Лидары: [LD19](https://www.elecrow.com/download/product/SLD06360F/LD19_Datasheet_V1.0.pdf), [RPLIDAR C1](https://files.waveshare.com/wiki/RPLIDAR-C1/SLAMTEC_rplidar_datasheet_C1_v1.0_en.pdf), [протокол RPLIDAR](https://files.seeedstudio.com/wiki/SLAMRadar/S3/series_protocol_LR001_SLAMTEC_rplidar_series_protocol_v1.0_en.pdf), [STL-19P (D500)](https://www.waveshare.com/wiki/D500_LiDAR_Kit)
- Драйверы без ROS: [`lds2d`](https://pypi.org/project/lds2d/) (LD19/STL19P/C1, на железе не проверен), [`rplidarc1`](https://pypi.org/project/rplidarc1/), [Slamtec SDK](https://github.com/Slamtec/rplidar_sdk). Свой парсер — ~150 строк.
- ToF: [VL53L5CX](https://www.st.com/resource/en/datasheet/vl53l5cx.pdf), [UM2884](https://www.pololu.com/file/0J1885/um2884-a-guide-to-using-the-vl53l5cx-multizone-timeofflight-ranging-sensor-with-wide-field-of-view-ultra-lite-driver-uld-stmicroel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), [UM3109 (L8CX)](https://www.pololu.com/file/0J2030/um3109-a-guide-for-using-the-vl53l8cx-lowpower-highperformance-timeofflight-multizone-ranging-sensor-stmicroelectronics.pdf)
- Драйверы ToF: [sensebox/CircuitPython_VL53LxCX](https://github.com/sensebox/CircuitPython_VL53LxCX) (L5CX и L8CX, через Blinka), [pimoroni/vl53l5cx-python](https://github.com/pimoroni/vl53l5cx-python) (только L5CX), [ST STSW-IMG042](https://www.st.com/en/embedded-software/stsw-img042.html)
- Pololu: [выключатели](https://www.pololu.com/category/121/pololu-power-switches), [D24V90F5](https://www.pololu.com/product/2866), [D36V50F12](https://www.pololu.com/product/4095), [D36V50F6](https://www.pololu.com/product/4092), [37D #4754](https://www.pololu.com/product/4754)
- RoboClaw: [руководство](https://downloads.basicmicro.com/docs/roboclaw_user_manual.pdf), [даташит 2x30A](https://downloads.basicmicro.com/docs/roboclaw_datasheet_2x30A.pdf); копии в `datasheet/`
- Raspberry Pi 4: [питание и GPIO](https://www.raspberrypi.com/documentation/computers/raspberry-pi.html#power-supply), [UART](https://www.raspberrypi.com/documentation/computers/configuration.html#configure-uarts), [overlays README](https://github.com/raspberrypi/firmware/blob/master/boot/overlays/README), [даташит](https://datasheets.raspberrypi.com/rpi4/raspberry-pi-4-datasheet.pdf), [цены](https://www.raspberrypi.com/news/a-new-3gb-raspberry-pi-4-for-83-75-and-more-memory-driven-price-increases/), [загрузка с USB](https://www.raspberrypi.com/documentation/computers/raspberry-pi.html#usb-mass-storage-boot)
- Jetson: [спецификация несущей платы](https://developer.nvidia.com/downloads/assets/embedded/secure/jetson/orin_nano/docs/jetson_orin_nano_devkit_carrier_board_specification_sp.pdf) (копия в `datasheet/`), [форум о J3/R560](https://forums.developer.nvidia.com/t/orin-nano-official-devkit-rtc-battery-connector-resistor-tidbits/366189)
- Провод: [таблица Cooner](https://www.coonerwire.com/amp-chart/)

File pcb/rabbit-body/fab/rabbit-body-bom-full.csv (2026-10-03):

Qty | Designator | Value | Footprint | LCSC | MPN / description | Assembly
1 | U4 | D24V90F5 | Pololu_D24V90F5 |  | Pololu D24V90F5 #2866 | owner's module, mounted on standoffs / pins
1 | U5 | D36V50F12 | Pololu_D36V50Fx |  | Pololu D36V50F12 #4095 | owner's module, mounted on standoffs / pins
1 | U6 | D36V50F6 | Pololu_D36V50Fx |  | Pololu D36V50F6 #4092 | owner's module, mounted on standoffs / pins
1 | U2 | Pololu 2813 | Pololu_BigPushbutton_HP |  | Pololu Big Pushbutton Power Switch HP #2813 | owner's module, mounted on standoffs / pins
1 | MOD1 | Raspberry Pi 4 | RaspberryPi4_Standoffs |  | Raspberry Pi 4 Model B + 4x M2.5x6 standoffs | owner's module, mounted on standoffs / pins
1 | U1 | RoboClaw 2x30A | RoboClaw_2x30A |  | Basicmicro RoboClaw 2x30A + 4x M3x6 standoffs | owner's module, mounted on standoffs / pins
1 | R37 | 1.5k | R_0603_1608Metric | C22843 | 0603 1.5k 1% | JLCPCB SMT
5 | R10,R11,R12,R13,R16 | 100 | R_0603_1608Metric | C22775 | 0603 100 1% | JLCPCB SMT
6 | R17,R19,R21,R23,R25,R26 | 100k | R_0603_1608Metric | C25803 | 0603 100k 1% | JLCPCB SMT
6 | C2,C3,C5,C10,C11,C12 | 100nF | C_0603_1608Metric | C14663 | 100nF X7R/X5R | JLCPCB SMT
3 | R28,R31,R39 | 10k | R_0603_1608Metric | C25804 | 0603 10k 1% | JLCPCB SMT
2 | R2,R4 | 10mR 2W | R_Shunt_2512_Kelvin | C105366 | FMF25FPJR010-LH | JLCPCB SMT
1 | C8 | 10nF | C_0603_1608Metric | C57112 | 10nF X7R/X5R | JLCPCB SMT
5 | C4,C6,C7,C9,C13 | 10uF | C_0805_2012Metric | C15850 | 10uF X7R/X5R | JLCPCB SMT
7 | R14,R15,R18,R20,R22,R24,R36 | 1k | R_0603_1608Metric | C21190 | 0603 1k 1% | JLCPCB SMT
4 | R32,R33,R34,R35 | 220 | R_0603_1608Metric | C22962 | 0603 220 1% | JLCPCB SMT
1 | R1 | 2mR 3W | R_Shunt_2512_Kelvin | C154685 | LR2512-23R002F4 | JLCPCB SMT
2 | R27,R40 | 330 | R_0603_1608Metric | C23138 | 0603 330 1% | JLCPCB SMT
3 | R29,R30,R38 | 4.7k | R_0603_1608Metric | C23162 | 0603 4.7k 1% | JLCPCB SMT
1 | R3 | 5mR 3W | R_Shunt_2512_Kelvin | C154688 | LR2512-23R005F4 | JLCPCB SMT
3 | Q1,Q2,Q3 | AO3400A | SOT-23 | C20917 | AO3400A | JLCPCB SMT
1 | U9 | DS3231SN | SOIC-16W_7.5x10.3mm_P1.27mm | C9866 | DS3231SN#T&R | JLCPCB SMT
1 | U3 | INA4235 | TI_DSBGA-16_YBJ_1.5x1.5mm_P0.4mm | C33440856 | INA4235AIYBJR | JLCPCB SMT
5 | D2,D3,D4,D5,D6 | LED green | LED_0603_1608Metric | C12624 | KT-0603G | JLCPCB SMT
1 | U8 | PCA9685PW | TSSOP-28_4.4x9.7mm_P0.65mm | C2678753 | PCA9685PW,118 | JLCPCB SMT
1 | D1 | SMBJ20A | D_SMB | C151922 | SMBJ20A | JLCPCB SMT
1 | D7 | SMBJ20CA | D_SMB | C151921 | SMBJ20CA | JLCPCB SMT
1 | U7 | TPS73733 | SOT-223-6 | C31334 | TPS73733DCQR | JLCPCB SMT
1 | C1 | 1000uF 35V | CP_Radial_D12.5mm_P5.00mm | C346962 | NXB 35V 1000uF 12.5x25 (or Panasonic EEU-FR1V102) | hand-solder (order from LCSC/JLC parts)
1 | C14 | 470uF 16V | CP_Radial_D8.0mm_P3.50mm | C19270651 | 470uF 16V polymer 8x12 | hand-solder (order from LCSC/JLC parts)
1 | F7 | ATO (spare) | Fuseholder_ATO_Keystone_3557x2 | C2680614 | 2x Keystone 3557 + ATO (spare) | hand-solder (order from LCSC/JLC parts)
1 | F2 | ATO 10A | Fuseholder_ATO_Keystone_3557x2 | C2680614 | 2x Keystone 3557 + ATO 10A | hand-solder (order from LCSC/JLC parts)
1 | F1 | ATO 15A | Fuseholder_ATO_Keystone_3557x2 | C2680614 | 2x Keystone 3557 + ATO 15A | hand-solder (order from LCSC/JLC parts)
1 | F6 | ATO 2A | Fuseholder_ATO_Keystone_3557x2 | C2680614 | 2x Keystone 3557 + ATO 2A | hand-solder (order from LCSC/JLC parts)
2 | F3,F4 | ATO 5A | Fuseholder_ATO_Keystone_3557x2 | C2680614 | 2x Keystone 3557 + ATO 5A | hand-solder (order from LCSC/JLC parts)
1 | F5 | ATO 7.5A | Fuseholder_ATO_Keystone_3557x2 | C2680614 | 2x Keystone 3557 + ATO 7.5A | hand-solder (order from LCSC/JLC parts)
1 | BT1 | CR1220 | BatteryHolder_Keystone_3001_1x12mm |  | Keystone 3001 holder (not at LCSC: Digi-Key or Mouser) + CR1220 cell | hand-solder (order from LCSC/JLC parts)
1 | J5 | E-stop loop | PinHeader_1x02_P2.54mm_Vertical | C53055672 | 1x2 header + jumper | hand-solder (order from LCSC/JLC parts)
1 | J6 | ENC left | JST_XH_B4B-XH-A_1x04_P2.50mm_Vertical | C144395 | JST B4B-XH-A | hand-solder (order from LCSC/JLC parts)
1 | J7 | ENC right | JST_XH_B4B-XH-A_1x04_P2.50mm_Vertical | C144395 | JST B4B-XH-A | hand-solder (order from LCSC/JLC parts)
1 | J17 | Jetson UART | JST_PH_B3B-PH-K_1x03_P2.00mm_Vertical | C131339 | JST B3B-PH-K-S | hand-solder (order from LCSC/JLC parts)
1 | J3 | Pi 40-pin | IDC-Header_2x20_P2.54mm_Vertical | C48687632 | BH254V-40P box header | hand-solder (order from LCSC/JLC parts)
1 | J18 | Pi fan 5V | JST_PH_B2B-PH-K_1x02_P2.00mm_Vertical | C131337 | JST B2B-PH-K-S | hand-solder (order from LCSC/JLC parts)
1 | J4 | RoboClaw I/O | PinHeader_2x05_P2.54mm_Vertical | C225520 | 2x5 2.54 pin header | hand-solder (order from LCSC/JLC parts)
4 | J8,J9,J10,J11 | ToF | JST_PH_B5B-PH-K_1x05_P2.00mm_Vertical | C157993 | JST B5B-PH-K-S | hand-solder (order from LCSC/JLC parts)
1 | J19 | USB hub 7-36V | JST_XH_B2B-XH-A_1x02_P2.50mm_Vertical | C158012 | JST B2B-XH-A | hand-solder (order from LCSC/JLC parts)
1 | J21 | XT30 JETSON | AMASS_XT30PW-F_1x02_P2.50mm_Horizontal | C2913282 | AMASS XT30PW-F | hand-solder (order from LCSC/JLC parts)
1 | J1 | XT60 BAT | AMASS_XT60-M_1x02_P7.20mm_Vertical | C19268037 | AMASS XT60PB-M vertical | hand-solder (order from LCSC/JLC parts)
1 | J13 | bumpers front | JST_XH_B2B-XH-A_1x02_P2.50mm_Vertical | C158012 | JST B2B-XH-A | hand-solder (order from LCSC/JLC parts)
1 | J14 | bumpers rear | JST_XH_B2B-XH-A_1x02_P2.50mm_Vertical | C158012 | JST B2B-XH-A | hand-solder (order from LCSC/JLC parts)
1 | J15 | button | JST_XH_B5B-XH-A_1x05_P2.50mm_Vertical | C157991 | JST B5B-XH-A | hand-solder (order from LCSC/JLC parts)
1 | J12 | lidar C1 | JST_PH_B4B-PH-K_1x04_P2.00mm_Vertical | C131334 | JST B4B-PH-K-S | hand-solder (order from LCSC/JLC parts)
1 | J22 | servo 0 | PinHeader_1x03_P2.54mm_Vertical | C49257 | 1x3 2.54 pin header | hand-solder (order from LCSC/JLC parts)
1 | J23 | servo 1 | PinHeader_1x03_P2.54mm_Vertical | C49257 | 1x3 2.54 pin header | hand-solder (order from LCSC/JLC parts)
1 | J24 | servo 2 | PinHeader_1x03_P2.54mm_Vertical | C49257 | 1x3 2.54 pin header | hand-solder (order from LCSC/JLC parts)
1 | J25 | servo 3 | PinHeader_1x03_P2.54mm_Vertical | C49257 | 1x3 2.54 pin header | hand-solder (order from LCSC/JLC parts)
1 | J20 | spare out | TerminalBlock_Phoenix_MKDS-1,5-2-5.08_1x02_P5.08mm_Horizontal | C474952 | KF128-5.08-2P | hand-solder (order from LCSC/JLC parts)
1 | J16 | status LED | JST_PH_B2B-PH-K_1x02_P2.00mm_Vertical | C131337 | JST B2B-PH-K-S | hand-solder (order from LCSC/JLC parts)

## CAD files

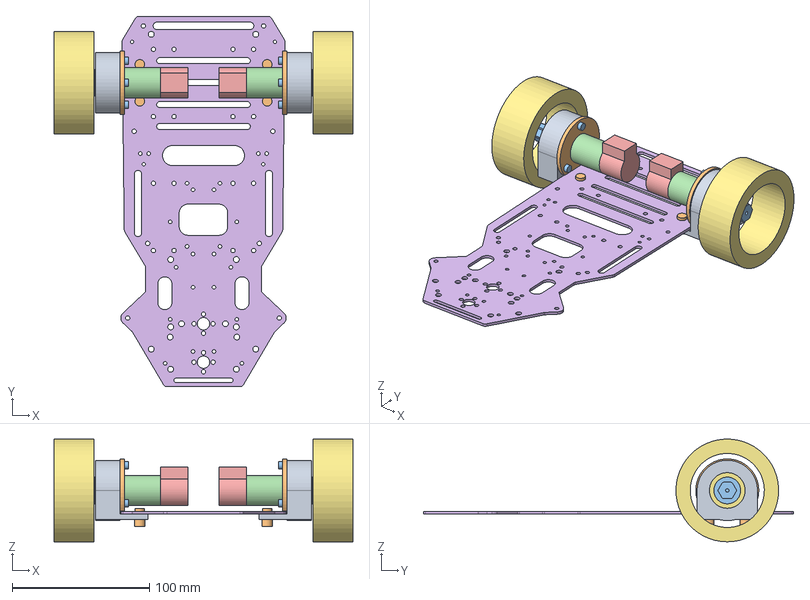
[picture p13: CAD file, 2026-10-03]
cad/drive/drive-assembly.step
218.0 x 269.9 x 74.8 mm
left_bracket
left_motor_flange
left_stub_axle
left_inner_spacer
left_oldham_hub
left_oldham_disc
left_bearing_1
left_bearing_2
left_circlip
left_gearhead_screw_0
left_gearhead_screw_1
left_gearhead_screw_2
left_m4_foot_0
left_m4_foot_1
left_m3_flange_0
left_m3_flange_1
left_m3_flange_2
left_gearhead
left_motor
right_bracket
right_motor_flange
right_stub_axle
right_inner_spacer
right_oldham_hub
right_oldham_disc
right_bearing_1
right_bearing_2
right_circlip
right_gearhead_screw_0
right_gearhead_screw_1
right_gearhead_screw_2
right_m4_foot_0
right_m4_foot_1
right_m3_flange_0
right_m3_flange_1
right_m3_flange_2
right_gearhead
right_motor
deck1
left_rear_tyre_envelope
right_rear_tyre_envelope

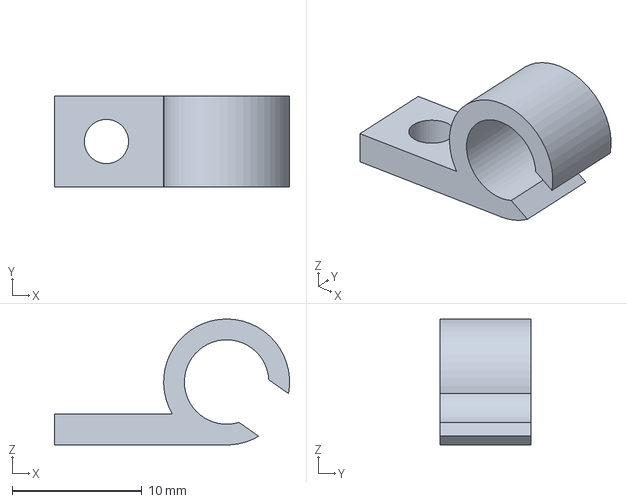
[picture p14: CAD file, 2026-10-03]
cad/brackets/cable_clip.step
18.1 x 7.00 x 9.70 mm

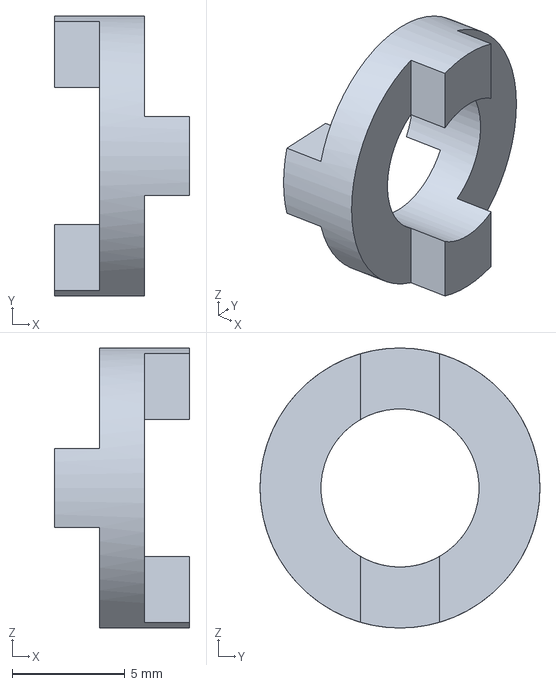
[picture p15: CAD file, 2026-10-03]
cad/drive/oldham_disc.step
6.00 x 12.4 x 12.4 mm

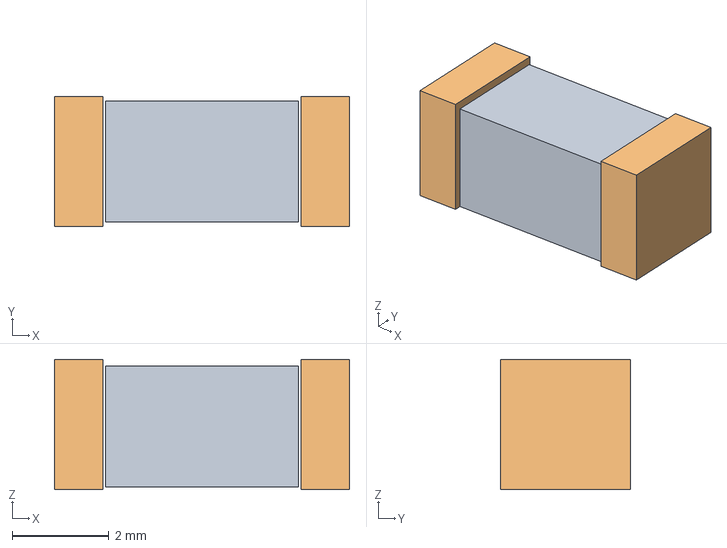
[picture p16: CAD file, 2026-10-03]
pcb/rabbit-body/3d/fuse_2410.step
6.10 x 2.69 x 2.69 mm

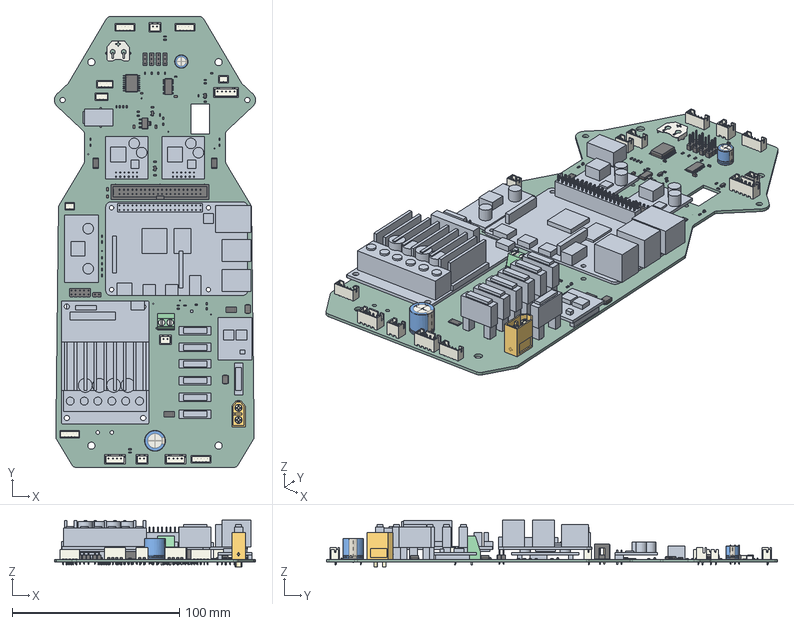
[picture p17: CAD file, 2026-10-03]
pcb/rabbit-body/rabbit-body.step
120.5 x 269.9 x 27.9 mm
XT60 male v9
TerminalBlock_Phoenix_MKDS-1,5-2-5.08_1x02_P5.08mm_Horizontal
R_0603_1608Metric x 31
JST_B5B_PH_K x 4
LED_0603_1608Metric x 5
PinHeader_1x03_P254mm_Vertical x 4
C_0805_2012Metric x 5
JST_B2B_XH_A x 3
C_0603_1608Metric x 7
PinHeader_1x02_P254mm_Vertical
JST_B3B_PH_K
PinHeader_2x05_P254mm_Vertical
JST_B4B_XH_A x 2
SOT-223
R_2512_6332Metric x 4
CP_Radial_D125mm_P500mm
JST_B5B_XH_A
SOT-23 x 3
D_SMB x 2
JST_B4B_PH_K
JST_B2B_PH_K x 2
SOIC-16W_7.5x10.3mm_P1.27mm
Keystone_3001_1x12mm
IDC_Header_2x20_P254mm_Vertical
CP_Radial_D80mm_P350mm
TSSOP-28_4.4x9.7mm_P0.65mm
rabbit-body_PCB

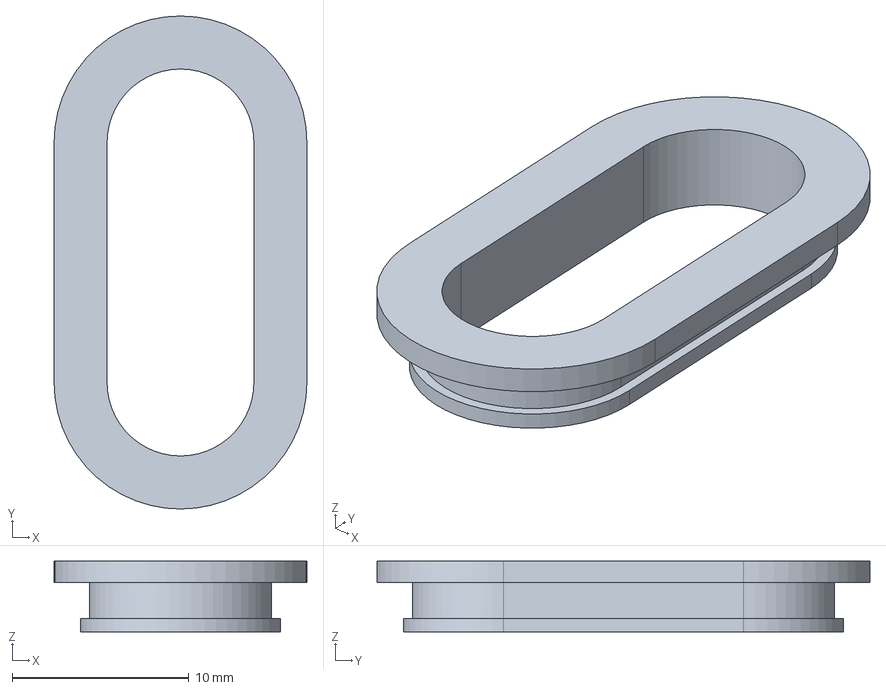
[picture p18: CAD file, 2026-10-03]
cad/brackets/slot_grommet.step
14.3 x 27.9 x 4.00 mm

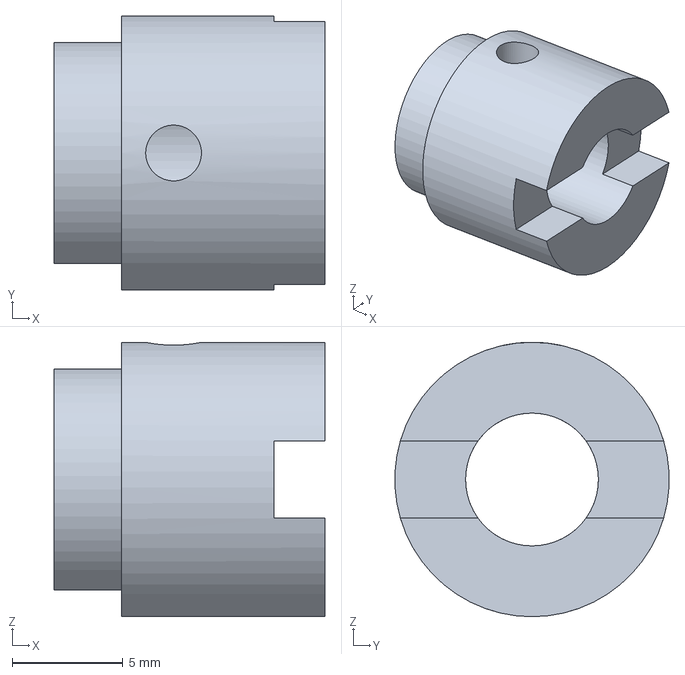
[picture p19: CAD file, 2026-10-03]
cad/drive/oldham_hub_faulhaber.step
12.2 x 12.4 x 12.4 mm

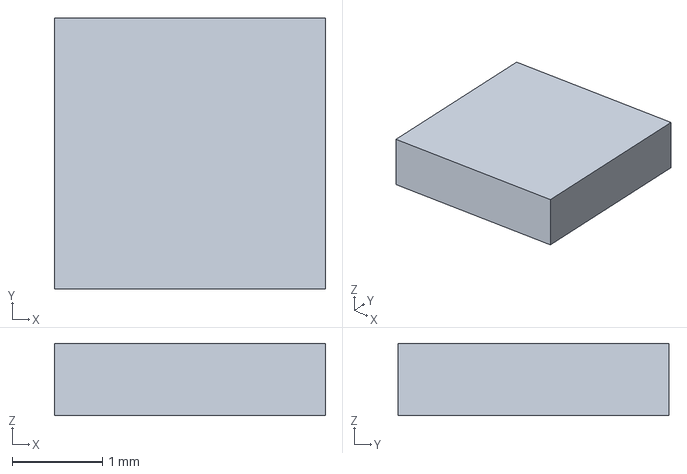
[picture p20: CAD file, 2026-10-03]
pcb/rabbit-body/3d/wson12_3x3.step
3.00 x 3.00 x 0.8 mm

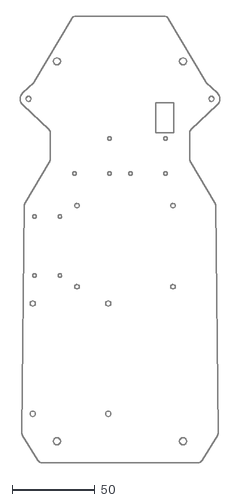
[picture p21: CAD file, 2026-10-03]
pcb/rabbit-body/outline.dxf
120.5 x 269.9

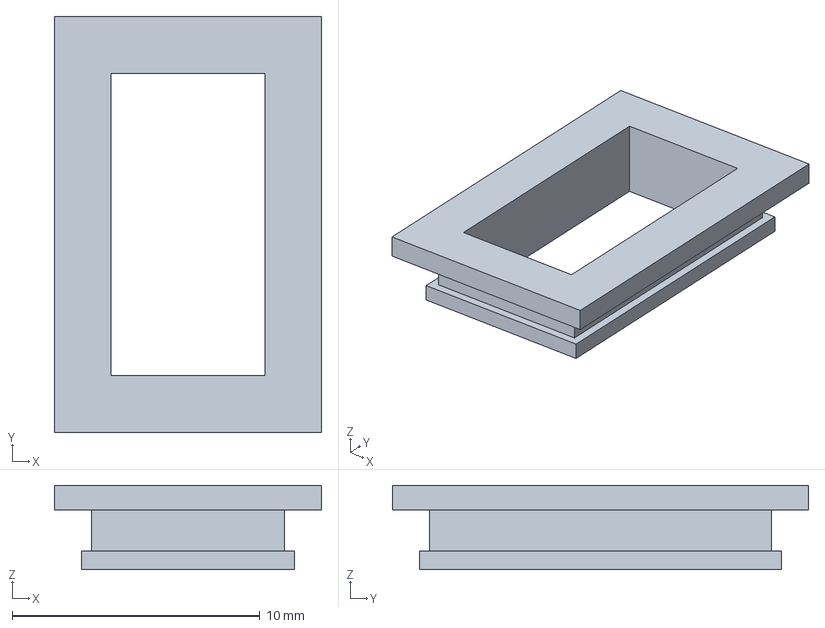
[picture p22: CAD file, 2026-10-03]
cad/brackets/zed_grommet.step
10.8 x 16.8 x 3.40 mm

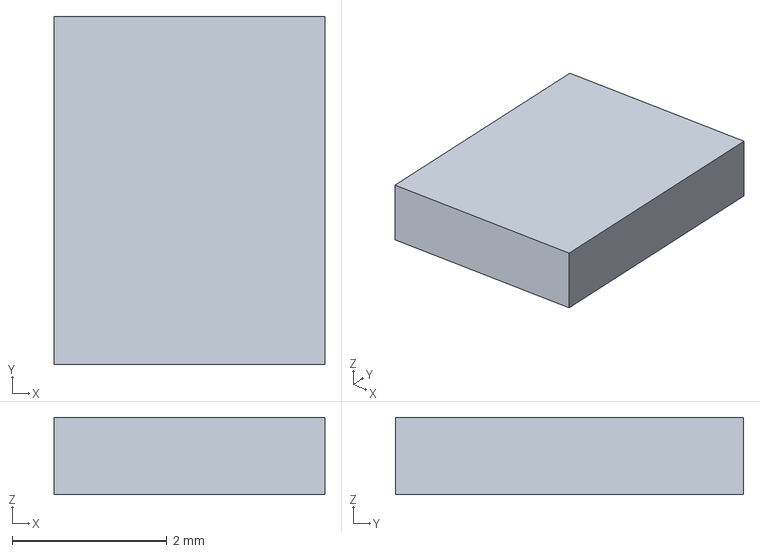
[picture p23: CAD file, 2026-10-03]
pcb/rabbit-body/3d/vqfn16_3.5x4.5.step
3.50 x 4.50 x 1.00 mm

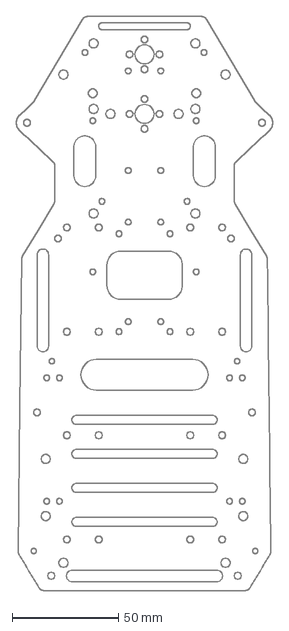
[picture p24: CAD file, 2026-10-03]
pcb/rabbit-body/kit_plate.dxf
120.5 x 269.9 mm

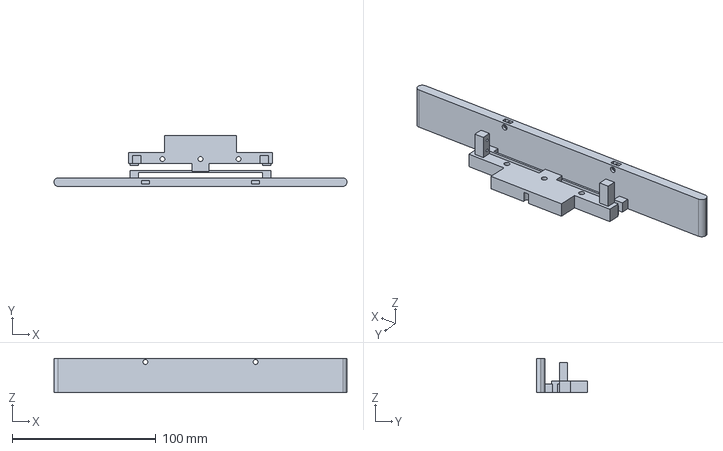
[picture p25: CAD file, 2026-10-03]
cad/brackets/bumper_front.step
204.0 x 35.5 x 24.0 mm

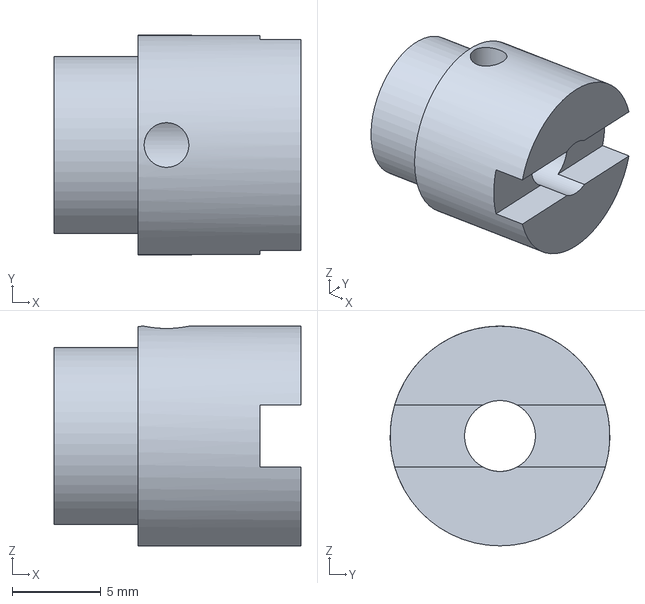
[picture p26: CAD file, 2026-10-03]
cad/drive/oldham_hub_maxon.step
13.9 x 12.4 x 12.4 mm

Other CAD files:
pcb/rabbit-body/3d/vqfn40_5x7.step
cad/brackets/pcb_comb_rear.step
cad/drive/motor_flange_faulhaber.step
pcb/rabbit-body/3d/rpi4.step
cad/brackets/bumper_front.3mf
cad/brackets/bumper_rear.3mf
cad/brackets/bumper_rear.step
cad/brackets/cable_clip.3mf
cad/brackets/cap_clamp.3mf
cad/brackets/cap_clamp.step
cad/brackets/lidar_mast.3mf
cad/brackets/lidar_mast.step
cad/brackets/pcb_comb_front.3mf
cad/brackets/pcb_comb_front.step
cad/brackets/pcb_comb_rear.3mf
cad/brackets/power_button_panel.3mf
cad/brackets/power_button_panel.step
cad/brackets/rear_camera_mount.3mf
cad/brackets/rear_camera_mount.step
cad/brackets/slot_grommet.3mf
cad/brackets/tof_pair.3mf
cad/brackets/tof_pair.step
cad/brackets/xt60_strain_relief.3mf
cad/brackets/xt60_strain_relief.step
cad/brackets/zed_grommet.3mf
cad/drive/bracket.step
cad/drive/bracket_print.3mf
cad/drive/bracket_print.stl
cad/drive/inner_spacer.step
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

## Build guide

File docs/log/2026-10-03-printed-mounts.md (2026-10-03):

# 2026-10-03 Printed mounts for Rabbit 2.0

Offline (the robot was off). Parametric build123d parts for the Rabbit 2.0 sensors, to be printed on a Bambu Lab P2S, with a fit check against the chassis model. Everything is in `cad/brackets/`; the print sheet is `cad/brackets/README.md`; the Russian summary is `reports/2026-10-03-mounts.md`. No robot or Forge code changed.

## Parts

| Part | Holds | Mounts on |
|---|---|---|
| `tof_pair` ×2 | two VL53L8CX on Pololu #3419, yaw ±22°, pitch +15°, 60 mm above the floor | the bumper backbone, 3× M3 from below into inserts |
| `bumper_front`, `bumper_rear` | a compliant bar and two Omron D2F-01L, struck by M3 grub screws | bottom plate edge, 3× M3 into inserts |
| `lidar_mast` | RPLIDAR C1, scan plane 220 mm above the floor | top plate between the ZED and the battery, 2× M3 + 2× M2.5 |
| `power_button_panel` | 16 mm 2NO lit button + 5 mm status LED | the mast's left side |
| `rear_camera_mount` | Camera Module 3 Wide, 142 mm high, 15° down | top plate rear slot, 2× M3 |
| `cable_clip` ×6 | bundles up to 6.5 mm | any 3.2 mm plate hole |

All PETG and support-free, ~6 h of printing in total; the build123d MCP printability analysis leaves only small bridges.

Vendor dimensions used:
- Slamtec C1 datasheet v1.0, fig. 4-1: 55.6 mm base, M2.5 at 43 mm, ≤ 4 mm deep, laser 29.8 mm above the base.
- Pololu #3419 dimension drawing: 12.7 × 22.86 mm, M2 holes 17.78 mm apart.
- Omron D2F datasheet: hinge lever OP 6.8 ± 1.5 mm from the hole line, FP ≤ 10, OT ≥ 0.55, M2 holes 6.5 mm apart.
- Raspberry Pi Camera Module 3 Wide mechanical drawing: M2 holes 21 × 12.5 mm.
- NEEWER PS099E: 111 × 73 × 56.7 mm.
- Alfa AWUS036ACM: 62 × 85.3 × 24 mm.

The PDFs were read from the vendors' sites and not kept in the repo.

## Chassis measurements (from `model/chassis.step`)

- **Plates.** The two kit plates are the same 2 mm part, 120.5 × 269.9 mm, centreline x = 2.48. Their holes are 3.2 mm (M3), 4.3 mm (the M4 corner standoffs), 2.7 mm and 2.5 mm, plus slots.
- **Wheels.** Wheelbase 171.5 mm and rear track 167.4 mm, which match `lib/geometry.py`. Tyres Ø74.9 × 29.2 mm.
- **Steering.** Kingpins at (57.74, −88.38) and (−52.78, −88.38); the wheel centre is 29.27 mm outboard of the kingpin. Steered 40° inward, a front tyre reaches 145.3 mm ahead of the kingpin line (y −145.3), 7 mm beyond the plate's front edge. Anything in front of the plate has to clear that.
- **Floor.** The model is not level: the front tyres touch at z 4.4, the rear ones at 7.0.
- **Frame.** Forward is −Y and the robot's left is +X. The PCB agent's board frame (`pcb/rabbit-body/gen/outline.json`) mirrors X and Y.

## The robot is not the kit

The kit's standoffs are 50 mm, which puts the top plate 75 mm above the floor. The robot's top plate is at ~122 mm: the ZED's optical centre is at 137 mm (`CAMERA_HEIGHT`) and the camera is 30.3 mm tall and sits on the plate; blog photos #142–144 agree. So `assembly.py` lifts the top plate by 46.6 mm. It adds boxes for:
- the ZED (tripod screw in the plate's 9 mm hole 45.9 mm behind the front edge);
- the V-mount plate (estimate);
- the battery.

Placing the ZED that way puts its lens about 10 mm ahead of `CAMERA_TO_REAR_AXLE` (0.1845 m). The ZED field-of-view check also sees the top plate's own front tab at the bottom of the ZED image. The ZED's real position on the plate should be measured; it affects the mast's front clearance (1 mm assumed).

## Decisions

- **ToF pitched 15° up.** At 60 mm the lowest of the 45° rows reaches a flat floor at 0.46 m. The 0–0.4 m zone the ToFs are for has no floor returns, and the safety loop needs no per-zone floor model. Low objects close in (below ~47 mm at 0.1 m) are left to the bumper and, further out, the ZED.
- **Two sensors per holder.** Four single holders did not fit next to the switches and the rear standoffs, so there is one twin holder per end. The rear one is the same print turned 180°.
- **Bumper as one compliant print.**
  - Two guided 40 × 1.25 × 6 mm PETG leaves from a central stub give ~0.7 N/mm; with the D2F's 0.78 N lever a switch trips at ~2 N.
  - Hard stops at 3.5 mm keep the lever from being crushed and the bar off the steered tyres.
  - The leaves stand vertical in the print so the layers run along the bending direction.
  - The switches stand upright on posts with the lever toward the bar. An M3 grub screw in the bar is the adjustable striker, because the lever's operating point varies ±1.5 mm between switches.
- **Scan plane at 220 mm.** The battery top is ~188.7 mm. Over the ~0.19 m to the battery's far corner the C1's scan-field flatness (0–1.5°) drops the plane by up to 5 mm, and the beam has a few mm of height, so ≥ 200 mm is needed. At 220 mm the whole lidar is above the battery (it can slide out), still within the report's 18–22 cm. The robot becomes 231.5 mm tall.
- **Power button on the mast.** There are no two free plate holes beside the mast for a separate box, and the rear strip is needed by the camera. Only the button's wires and the lidar lead go into the plate slots next to the mast foot.
- **No antenna mount.** The Alfa's 19 cm antennas would cross the scan plane (~3° shadow each). Keep the tips below 205 mm or mask the sectors.

## Checks (`cad/brackets/assembly.py`, ~10 min)

The results are in `cad/brackets/renders/fit_report.json`.
- **Screws.** All 12 plate screws land in a measured hole or slot of the right size.
- **Overlaps.** No part or hardware overlaps anything: 7 printed parts, sensors, switches, lidar, button and camera, against each other, the 134 chassis solids and the envelopes. The threshold is 0.5 mm³.
- **Steering.** Tyre envelopes swept about the kingpins in 2.5° steps:
  - to ±35°: the smallest gap to the bumper is 6.8 mm;
  - to ±40°: 4.5 mm, and 7.2 mm for the bar pushed to its stops.
- **Fields of view.** Nothing new in any of them:
  - 4 ToF frustums;
  - the lidar band, ±(3 mm + r·tan 1.5°) over 31–500 mm;
  - the ZED frustum, level and pitched 10° down;
  - the rear camera frustum.

## Footprint change

With the bumpers on, the footprint grows:
- front: 0.2452 m from the rear axle (was 0.2245);
- rear: 0.072 m (was 0.07);
- half width: 0.102 m (was 0.10).

`Footprint` in `lib/safety.py` and `front_overhang` in `lib/planner.py` have to follow when the bumpers are fitted.

## Pitfalls met

- **3MF export.** build123d's `Mesher` refused to write a 3MF ("mesh is invalid") for solids that were valid B-reps but had 0.01 mm sliver faces. These came from unions overlapping by 0.01 mm, or a hole tangent to a face. Overlap by ≥ 0.5 mm inside another solid, or not at all.
- **Insert depth.** The mast foot is 5 mm and an M3 × 5.7 insert needs 6: the first version would have pushed the inserts through the foot. The foot now has bosses there.

## Open

- **PCB-dependent parts.** Done in the update below, except the USB hub bracket.
- **Measurements on the robot.** The list is in the README, "Measure before printing": top plate and battery heights, the ZED and V-mount positions, free plate edges, the button's size.

## Update: the 3-deck stack and the body PCB (same day)

The owner confirmed a 3-deck stack, and the body PCB was finished (`reports/2026-10-03-body-pcb.md`):
- deck 1 is the lower kit plate;
- 45 mm brass standoffs;
- deck 2 is the PCB (bottom 69.8 mm above the floor);
- another 45 mm;
- deck 3 is the upper kit plate (top 118.4 mm).

Heights now use the PCB report's floor (front tyres, deck 1 top 24.8 mm). The assembly rebuilds the stack:
- deck 3 is lifted 41.6 mm from the kit;
- the steering posts are cut to 18 mm under the PCB;
- `pcb/rabbit-body/rabbit-body.step` is the board, all 266 solids, in every check.

What changed and why:
- **V-mount plate is long.** The 2026-10-03 side photo shows the owner's plate from ~26 to ~180 mm from deck 3's rear edge, about 17 mm thick. Its front end sat where the mast foot was (y −70…−33).
  - The mast moved forward into the strip between the ZED and the plate: foot at y −98…−57, screws in the 3.2 mm holes at y −92.55 and the 2.7 mm holes at y −65.96.
  - The battery top is now ~192 mm, so the scan plane went up to **230 mm**: lidar base at 200.2 mm, robot 241.5 mm tall.
  - The ZED is modelled from the same photo, with its back face 23 mm behind deck 3's front edge. That puts the lens ~0.24 m ahead of the rear axle; `CAMERA_TO_REAR_AXLE` says 0.1845, so the ZED position is still a measurement to make.
- **ToF heads under the PCB.** The PCB's nose and tail pass over the ToF pairs, and its edge connectors' pins reach 1.81 mm below the board. The first-run heads came up to ~80 mm above the floor (model), through the board.
  - The boards now lie landscape (head 10 mm lower) and the sensors moved from 60 to 57.8 mm above the floor.
  - The heads moved to ±19 mm and the bumper switches 2 mm outward to make room.
  - Gap to the lowest PCB feature: 3.5 mm front, 2.7 mm rear. The zone grid is turned 90°, so `T_base_tof` needs a 90° roll.
- **New parts from PCB report §10**, all clip-on or glued, since the board has no holes for them:
  - front and rear edge combs for the cables going over the edge to deck 1 (items 8–9);
  - an XT60 strain-relief post at the right edge (item 7);
  - a collar for the 1000 µF C1 (item 6);
  - a TPU grommet for the PCB's ZED cutout (item 11);
  - two TPU grommets for deck 3's 10.3 × 23.9 mm slots, the cable passthroughs between decks: ZED and lidar on the left, the button wires on the right inside the mast foot.
- **Brass, not printed:** 8 × M3 F-F 45 mm, 2 × M3 18 mm for the steering bracket, the Pi and RoboClaw standoffs. They are in the README's "Buy" table.
- **USB hub bracket (§10 item 12) not made.** Waveshare's drawing gives 72.2 × 47.8 × 27.6 mm (86 mm with ears), with ports on both long sides. Under deck 3 that leaves 17.4 mm above the PCB against the ≥ 20 mm §10 asks for. In the suggested place the hub would also cover both deck 3 cable slots and touch the front deck columns, and its plugs need ~35 mm on each long side. It needs a new place; the question is in `docs/open-issues.md`.
- **Camera ribbon.** The PCB report sends it up through deck 3's long slot at y 51, but the V-mount plate covers that slot, so the ribbon goes over deck 3's rear edge.

**Checks after the change:**
- all 12 plate screws match;
- no overlap above 0.5 mm³ among the 13 printed parts, their hardware, the chassis, the PCB and the envelopes;
- steering gaps unchanged (4.5 mm at 40°, 7.2 mm with the bar pushed);
- the ToF, lidar, ZED and rear camera fields are clear.

The first run showed the slot grommets inside the hub bracket; that was one of the reasons to drop the bracket.

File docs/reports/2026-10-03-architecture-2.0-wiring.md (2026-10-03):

# Rabbit 2.0: проводка, выводы Pi, шины, INA4235

Приложение к [`2026-10-03-architecture-2.0.md`](2026-10-03-architecture-2.0.md). Покупки — в [`-bom.md`](2026-10-03-architecture-2.0-bom.md), программа — в [`-body.md`](2026-10-03-architecture-2.0-body.md).

**Схемы** генерирует `media/wiring-2.0.py` (три листа) и `media/power-2.0.py`. Подписи на английском.

| Лист | Что на нём |
|---|---|
| [`media/wiring-2.0-overview.svg`](media/wiring-2.0-overview.svg) | все устройства и связи, цвет — тип линии (батарея, DC, I2C, UART, USB, Ethernet, CSI, GPIO, ШИМ, энкодер, измерительные пары INA) |
| [`media/wiring-2.0-signals.svg`](media/wiring-2.0-signals.svg) | 40-контактный разъём Pi с именем цепи на каждом выводе и разъёмы всех устройств с теми же именами; MOSFET-ключи; `config.txt` |
| [`media/wiring-2.0-power.svg`](media/wiring-2.0-power.svg) | силовая часть: клеммы, предохранители, шунты, преобразователи, сечения проводов и разъёмы, правила земли |
| [`media/power-2.0.svg`](media/power-2.0.svg) | токи и бюджет по ветвям; INA4235 одним блоком с четырьмя каналами и шунтами в своих ветвях |

## Выводы Raspberry Pi 4

**Главное правило:** выходы, от которых зависит безопасность (E-stop, EN Jetson, OFF выключателя, питание ToF), стоят на GPIO9–27. При включении они подтянуты к земле (даташит Pi 4, табл. 5). Поэтому Pi, который грузится, завис до инициализации или выключен, означает: E-stop нажат, Jetson включён, главный выключатель включён.

| Вывод | GPIO | Функция | Куда |
|---|---|---|---|
| 1 | 3V3 | питание 3,3 В | PCA9685 VCC, DS3231 VIN, подтяжки бамперов и кнопки |
| 2, 4 | 5V | вход 5 В | D24V90F5 VOUT (два провода AWG20 ≤ 20 см) |
| 6, 9 | GND | земля | D24V90F5 GND |
| 3 / 5 | 2 / 3 | I2C1 SDA / SCL, 400 кГц | PCA9685 0x40, INA4235 0x41, DS3231 0x68 |
| 7 / 29 | 4 / 5 | I2C3 SDA / SCL | ToF передний левый (FL) |
| 31 / 26 | 6 / 7 | I2C4 SDA / SCL | ToF передний правый (FR) |
| 19 / 23 | 10 / 11 | I2C5 SDA / SCL | ToF задний левый (RL) |
| 15 / 16 | 22 / 23 | I2C6 SDA / SCL | ToF задний правый (RR) |
| 8 / 10 | 14 / 15 | UART0 TX / RX (PL011, `disable-bt`) | RoboClaw S1 (RX) / S2 (TX) |
| 24 / 21 | 8 / 9 | UART4 TX / RX | лидар RX / TX, 460800 |
| 32 / 33 | 12 / 13 | UART5 TX / RX, через 1 кОм | Jetson J14-3 (UART2_RXD) / J14-4 (UART2_TXD), отладочная консоль 115200 |
| 36 | 16 | `ESTOP_RUN`: выход, высокий = можно ехать | RoboClaw S3; 1 кОм от S3 к земле у разъёма RoboClaw |
| 11 | 17 | `SWITCH_OFF` (`gpio-poweroff`) | выключатель Pololu, вход OFF |
| 22 | 25 | `JETSON_OFF`: высокий = Jetson выключен | затвор Q1 → EN D36V50F12 |
| 12 | 18 | `TOF_PWR_OFF`: высокий = ToF обесточены | затвор Q2 → EN регулятора 3,3 В ToF |
| 13 | 27 | `BTN_LED` | затвор Q3 → подсветка кнопки |
| 35 | 19 | `STATUS_LED` | 330 Ом → светодиод → земля |
| 37 | 26 | `POWER_BTN`: вход, 10 кОм к 3V3 + 100 нФ | второй полюс кнопки |
| 38 | 20 | `BUMPER_FRONT`: 4,7 кОм к 3V3 + 100 нФ | NC-контакты передних бамперов последовательно, на землю |
| 40 | 21 | `BUMPER_REAR`: так же | задние бамперы |
| 18 | 24 | `INA_ALERT`, вход с подтяжкой | ALERT INA4235EVM (открытый сток) |
| 14 | GND | | земля разъёма S RoboClaw |
| 17 / 20 | 3V3 / GND | | питание INA4235EVM |
| 25, 30, 34, 39 | GND | | лидар и задние ToF; передние ToF; J14-7 Jetson; бамперы, кнопка, светодиоды |
| 27 / 28 | 0 / 1 | ID_SD / ID_SC | не трогать (EEPROM HAT при загрузке); резерв |

Свободных GPIO нет, кроме 0/1. Если понадобятся INT датчиков ToF или вентилятор с ШИМ, сначала освобождаем UART5: консоль Jetson — удобство, не необходимость.

**`config.txt`** (Raspberry Pi OS 64-bit; текущий релиз — Trixie, ядро 6.18):

```
dtparam=i2c_arm=on,i2c_arm_baudrate=400000
dtoverlay=i2c3,pins_4_5,baudrate=400000
dtoverlay=i2c4,pins_6_7,baudrate=400000
dtoverlay=i2c5,pins_10_11,baudrate=400000
dtoverlay=i2c6,pins_22_23,baudrate=400000
dtoverlay=disable-bt
dtoverlay=uart4
dtoverlay=uart5
dtoverlay=i2c-rtc,ds3231
dtoverlay=gpio-poweroff,gpiopin=17
dtparam=watchdog=on
```

Плюс в systemd `RuntimeWatchdogSec=15`: аппаратный предел watchdog около 16 с. Загрузка с флешки USB: `BOOT_ORDER=0xf14`. SD-карты нет вовсе.

### Проверка ограничений Pi 4

Источники — документация Raspberry Pi; ссылки в `-bom.md`.

| Ограничение | Значение | Что из этого следует |
|---|---|---|
| UART и Bluetooth | Bluetooth занимает UART0 (PL011), на GPIO14/15 остаётся mini UART; его скорость зависит от частоты ядра | `disable-bt`: UART0 на 14/15 для RoboClaw. Bluetooth не нужен: геймпад подключён к браузеру оператора. UART4 (8/9) и UART5 (12/13) — тоже PL011. UART4 конфликтует только с SPI0, а SPI не используется |
| Аппаратный ШИМ | GPIO12/18 — канал 0, GPIO13/19 — канал 1, всего 2 независимых канала | не используем: серва на PCA9685, мотор лидара C1 управляется командой. GPIO12/13 заняты UART5 |
| Уровни | вся логика 3,3 В, входы не терпят 5 В | RoboClaw выдаёт 3,3 В и принимает 5 В. Лидар — 3,3 В TTL. Плата ToF Pololu поднимает линии к своему VIN, поэтому VIN = 3,3 В, не 5 В. EN преобразователей подтянут к VIN (до 16,8 В) — только через MOSFET |
| Ток GPIO | 16 мА на вывод, ~50 мА на все вместе | самая большая нагрузка — линия E-stop в 1 кОм к земле: 3,3 мА. Светодиоды ≤ 5 мА, подсветка кнопки — через Q3 |
| Ток 3V3 для периферии | официально не указан | на 3V3 Pi только логика: PCA9685, INA, DS3231, подтяжки, ≤ 20 мА. ToF (до 150 мА каждый) — со своего регулятора |
| USB | все порты вместе ~1,1–1,2 А | от Pi питается только флешка; Wi-Fi и USB RoboClaw — через хаб со своим питанием |
| 5 В через выводы | нет защитного диода; ниже 4,63 В Pi сообщает о недостатке напряжения | USB-C не подключать одновременно с питанием через выводы; короткие толстые провода; `get_throttled` в телеметрии |
| I2C | i2c1 с подтяжками 1,8 кОм; i2c3–6 без подтяжек; растягивание такта на BCM2711 ненадёжно | ToF на i2c3–6 (подтяжка — на плате Pololu). Внешний I2C1 суммарно ~1,1 кОм (1,8k ∥ 4,7k EVM ∥ 10k Adafruit ×2): допустимо, но если будут ошибки — снять подтяжки на одной плате |
| Температура | троттлинг ядер с 80 °C, полный с 85 °C | радиатор с вентилятором внутри корпуса робота, см. риски |

## Устройства и их разъёмы

### RoboClaw 2x30A

| Контакт | Куда | Примечание |
|---|---|---|
| S1 (RX) | Pi вывод 8, GPIO14 UART0 TX | 3,3 В, без преобразователя уровня |
| S2 (TX) | Pi вывод 10, GPIO15 UART0 RX | |
| S3 | Pi вывод 36, GPIO16 `ESTOP_RUN` | 1 кОм от S3 к GND **в разъёме у RoboClaw**: оборванный кабель = стоп |
| GND разъёма S | Pi вывод 14 | средние контакты +5 В не подключать |
| EN1 A / B, EN2 A / B | энкодеры левого / правого мотора: жёлтый / белый | A — ведущий канал вперёд; поменять можно в Motion Studio |
| `+` / `−` энкодеров | синий (Vcc) / зелёный (GND) обоих энкодеров | 5 В RoboClaw, по 10 мА на энкодер |
| B+ / B− | F1 → шунт 5 мОм → B+; B− → звезда | AWG16 ≤ 25 см, 1000 мкФ 35 В на клеммах |
| M1A/M1B, M2A/M2B | моторы | AWG18 скрученными парами; один мотор подключён наоборот |
| micro-USB | USB-хаб | Motion Studio и запасной порт |

**Настройки (Motion Studio или пакетные команды, затем запись в NVM командой 94):**
- packet serial 115200, адрес 0x80;
- **S3 = E-Stop без защёлки** (команда 74, 0x41). По умолчанию в последовательных режимах S3 — E-stop **с защёлкой**, а снять её можно только сбросом RoboClaw;
- M1/M2 max current 3 А (команды 133/134, единица 10 мА; чтение — 135/136);
- таймаут packet serial 0,5 с (команда 14; узел ставит его сам);
- **ограничения скважности для packet serial в RoboClaw нет.** «Fwd/Rev Limit» действует только в RC/аналоговом режиме. Поэтому `roboclaw.py` ограничивает скважность сам: 12 В / напряжение батареи, 0,71 при 16,8 В. Это изменение кода на потом.

**Линия E-stop.**
- Вход S3 активен низким уровнем, внутри подтянут вверх, порог «0» < 0,8 В (руководство RoboClaw).
- **Сама по себе такая линия не безопасна:** оборванный провод — это «едем».
- **Поэтому:**
  - резистор 1 кОм к земле прямо в разъёме S3 (против внутренней подтяжки получается < 0,5 В);
  - Pi держит линию высокой (3,3 мА), пока жив процесс `rabbit-safety`;
  - стоп наступает, если Pi не загрузился, процесс упал (ядро отпускает линию, она становится входом с подтяжкой к земле), провод оборван или Pi выключен.
- **Рекомендация из руководства** (внешняя подтяжка вверх для проводов > 150 мм) здесь заменена активным высоким уровнем от Pi: помехозащищённость та же.
- **Бамперы на линию E-stop не заводим.** Иначе робот, упёршийся бампером, не сможет отъехать: E-stop держит моторы, пока бампер нажат.

**USB или UART для управления.**
- Владелец решил USB. Но даташит RoboClaw 2x30A (`datasheet/RoboClaw 2x30A datasheet.pdf`, раздел USB) говорит:
  - USB — для настройки и отладки;
  - в электрически шумной среде порт «скорее всего отключится и не восстановится сам» без переподключения кабеля;
  - для управления предпочтителен TTL.
- **Поэтому разводим оба:**
  - UART0 — основной (`ROBOCLAW_PORT=/dev/ttyAMA0`);
  - USB — для Motion Studio и как запасной.
- Код уже выбирает USB, если он есть. Надо задать порт явно (вопрос владельцу).

### Энкодеры Pololu 37D (#4754)

| Провод | Назначение | Куда |
|---|---|---|
| красный / чёрный | мотор | M1A/M1B (левый), M2A/M2B (правый) |
| зелёный | GND энкодера | `−` разъёма энкодеров RoboClaw |
| синий | Vcc 3,5–20 В, ≤ 10 мА | `+` (5 В) разъёма энкодеров |
| жёлтый | A | EN1 A / EN2 A |
| белый | B | EN1 B / EN2 B |

**Счёт:**
- 64 CPR × 70 = 4480 отсчётов на оборот колеса;
- 5,26·10⁻⁵ м на отсчёт при колесе 75 мм;
- ~19 000 отсчётов на метр.

Сейчас энкодеры «читают 0». Вероятно, не подано питание (синий/зелёный) или A/B не на тех контактах. Проверить мультиметром: 5 В между синим и зелёным, и меандр на жёлтом при медленном вращении колеса рукой.

### PCA9685 и руль

| Контакт | Куда |
|---|---|
| VCC / GND | Pi вывод 1 (3V3) / вывод 14 |
| SDA / SCL | Pi выводы 3 / 5 (I2C1) |
| OE | не подключать (на плате подтянут к земле, выходы включены) |
| V+ / GND (клеммы) | 6 В с выхода канала 2 INA (IN−), AWG18 / звезда |
| канал 0 | серва A50BHL: сигнал / красный / чёрный |

Адрес 0x40. Общий адрес ALLCALL 0x70 включён по умолчанию; это важно, только если появится TCA9548A на 0x70.

### INA4235EVM

| Контакт | Куда |
|---|---|
| J3: 3V3, GND | Pi вывод 17 / 20 |
| J3: SDA, SCL | Pi выводы 3 / 5 |
| J3: ALERT | Pi вывод 18, GPIO24 |
| SW1 / SW0 | A1 = GND, A0 = VS → 0x41 (как сейчас) |
| J6 | перемычка 1–2: EN = 3V3 |
| J1/J5 ch1 IN+/IN− | измерительная пара от внешнего шунта 2 мОм в цепи батареи |
| J1/J5 ch2 IN+/IN− | ток 6 В идёт через EVM, шунт 10 мОм на плате |
| J1/J5 ch3 IN+/IN− | измерительная пара от внешнего шунта 5 мОм в цепи моторов |
| J1/J5 ch4 IN+/IN− | ток 12 В Jetson идёт через EVM, шунт 10 мОм на плате |
| J1/J5 GND (контакты 1 и 6) | тонкий провод к звезде, только как опорная земля |

Номера контактов J3 и какой канал на какой клеммной колодке — по шелкографии EVM (руководство SBOU298, рис. 2-4). Сейчас разъём уже подключён к Jetson перемычками, и владелец знает, где какой провод.

### ToF (4× VL53L8CX на Pololu #3419)

**Подключение** — каждый датчик на своей шине I2C, все на адресе 0x29:
- FL — I2C3 (выводы 7/29);
- FR — I2C4 (31/26);
- RL — I2C5 (19/23);
- RR — I2C6 (15/16).

**Почему не одна шина:**
- нет смены адресов после каждой загрузки (драйвер L8CX её не умеет);
- датчики инициализируются параллельно: загрузка прошивки ~86 КБ занимает ~2,2 с на 400 кГц для каждого;
- зависшая шина выключает один датчик, а не все;
- полный кадр 8×8 со всеми выходами ~1440 Б, четыре датчика на 15 Гц не помещаются в одну шину 400 кГц.

| Контакт платы | Куда |
|---|---|
| VIN / GND | регулятор 3,3 В для ToF (~1 А, EN ← Q2) / земля Pi (выводы 25, 30) |
| SDA / SCL | своя шина, скрученные пары SDA+GND и SCL+GND, ≤ 40 см |
| SPI/I2C | на GND (иначе плата в режиме SPI) |
| LPn, INT, SYNC | не подключать |

**Монтаж:**
- спереди два датчика, развёрнуты на ±22° от оси, на высоте ~5–8 см (ниже кадра ZED);
- сзади так же;
- углы обзора 45°×45°: спереди и сзади получается по ~90°.

### Лидар RPLIDAR C1

| Контакт | Куда |
|---|---|
| VCC 5V / GND | шина 5 В (D24V90F5), 0,8 А при старте, пульсации ≤ 150 мВ / звезда |
| TX | Pi вывод 21, GPIO9 UART4 RX |
| RX | Pi вывод 24, GPIO8 UART4 TX |

- 460800 бод, TTL 3,3 В;
- сам не шлёт данные: нужна команда старта;
- USB-адаптер из комплекта — для проверки на ноутбуке;
- ставить на мачту на 18–22 см.

### Бамперы, кнопка, светодиоды

**Бамперы** — 2 спереди и 2 сзади, Omron D2F-01L:
- COM → земля, NC последовательно → GPIO20 (перед) / GPIO21 (зад);
- 4,7 кОм к 3V3 и 100 нФ к земле у Pi;
- в покое на входе 0, нажатие или обрыв дают 1.

**Кнопка питания** — двухполюсная, без фиксации, с подсветкой:
- полюс 1: вход A выключателя Pololu ↔ земля. Pololu документирует это как «нажатие только включает»;
- полюс 2: GPIO26 ↔ земля;
- подсветка: 5 В → кольцо → сток Q3.

**Светодиод состояния:** GPIO19 → 330 Ом → светодиод → земля.

### MOSFET-ключи

Q1–Q3 — логические N-канальные (2N7000, BSS138 или AO3400): затвор через 1 кОм от GPIO, 100 кОм затвор–исток, исток на землю.

| Ключ | Сток | GPIO | Высокий уровень = |
|---|---|---|---|
| Q1 | EN D36V50F12 (Jetson) | 25 | Jetson обесточен |
| Q2 | EN регулятора 3,3 В ToF | 18 | все ToF обесточены (сброс зависших) |
| Q3 | катод подсветки кнопки | 27 | подсветка горит |

У Pololu EN подтянут к VIN через 100 кОм: по умолчанию преобразователь включён, «0» < 0,6 В (D24V*) или < 1,2 В (D36V*) выключает. Подключать EN прямо к GPIO нельзя: подтяжка к 16,8 В пойдёт в вывод Pi.

### Jetson

| Разъём | Куда |
|---|---|
| J16 (DC 5,5/2,5 мм, центр +, 9–20 В, ≤ 3,5 А) | 12 В с выхода канала 4 INA, AWG18 ≤ 30 см |
| J15 RJ45 | Pi RJ45, Cat6 0,5 м. Адреса 10.77.0.2 (Jetson) и 10.77.0.1 (Pi), /30 |
| USB 3 | ZED 2i |
| J14 контакты 3 / 4 / 7 | UART5 Pi через 1 кОм / земля (отладочная консоль) |
| J3 (RTC) | **не распаян на dev kit**: нужно припаять разъём Molex PicoBlade 53398-0271 и резистор R560 (0402, 0 или 0,56 Ом) и подключить CR1225 с выводом PicoBlade. Предлагается не делать: время Jetson берёт с Pi (DS3231 + chrony) до старта Docker |

**Питание Jetson прямо от батареи** (J16 принимает 9–20 В):
- D36V50F12 при входе ниже 13,3 В выходит из стабилизации, это нижние ~15% заряда: на выходе ≈ вход минус падение, Jetson продолжает работать;
- преобразователь оставляем: он у владельца есть, гасит броски моторов и даёт EN;
- альтернатива — второй выключатель Pololu (Big MP #2812, 4 А) с входами ON/OFF от Pi вместо преобразователя.

### Pi: порты

| Порт | Куда |
|---|---|
| USB 3, порт 1 | Raspberry Pi Flash Drive 256 ГБ: загрузка, Forge, JetStream |
| USB 3, порт 2 | хаб Waveshare USB3.2-Gen1-HUB-4U (питание 7–36 В от F5): Wi-Fi Alfa AWUS036ACM на удлинителе, антенны снаружи корпуса; micro-USB RoboClaw |
| CSI | Camera Module 3 Wide, шлейф 15 контактов 1 мм, 300 мм (Adafruit #1648) |
| RJ45 | Jetson J15 |
| USB-C | **не подключать**, пока Pi питается через выводы 5 В |

## Силовая часть

Подробно — на [`media/wiring-2.0-power.svg`](media/wiring-2.0-power.svg).

**Цепочка:** площадка V-mount → XT60 → предохранитель 15 А → выключатель Pololu Big HP #2813 (TVS SMBJ20A на выходе) → шунт 2 мОм (канал 1) → блок предохранителей.

| Ветвь | Предохранитель | Путь | Провод |
|---|---|---|---|
| Моторы | 10 А | шунт 5 мОм (канал 3) → RoboClaw B+ | AWG16 ≤ 25 см |
| Руль | 7,5 А | D36V50F6 → EVM канал 2 → PCA9685 V+ | AWG18 |
| Мозг | 5 А | D36V50F12 → EVM канал 4 → Jetson J16 | AWG18 ≤ 30 см |
| Тело 5 В | 5 А (не 3 А: при 12,4 В на входе 5 В × 5 А — это ~2,3 А) | D24V90F5 → Pi, лидар, регулятор ToF, вентилятор | AWG18 вход, 2× AWG20 к Pi |
| USB-хаб | 2 А | клеммы хаба 7–36 В | AWG20 |
| Резерв | — | 4G / манипулятор | |

**Выключатель Pololu HP:**
- 4,5–32 В; 6 А длительно при плате 55 °C, 16 А — тепловой предел (MOSFET 150 °C);
- на роботе средний ток 2–3 А с короткими пиками до ~10 А, этого достаточно;
- Pololu предупреждает: это не аварийный выключатель, на входе нужен TVS или конденсатор.

**Земля** (правила на листе):
- одна звезда на отрицательной шине блока предохранителей, у каждой ветви свой обратный провод;
- минус никогда не разрывается предохранителем или выключателем;
- B− RoboClaw нельзя отключать, пока подключены USB или UART: обратный ток моторов пойдёт через логическую землю, даташит прямо пишет «damage will occur».

## INA4235: что говорит даташит и что меняем

Источники: `datasheet/INA4235.pdf` (SBOSAB5), `datasheet/INA4230EVM INA4235EVM INA423X Evaluation Module.pdf` (SBOU298).

| Вопрос | Ответ |
|---|---|
| Диапазон шунта | ±81,92 мВ (ADCRANGE = 0, шаг 2,5 мкВ) или ±20,48 мВ (шаг 625 нВ), выбирается на канал (CONFIG2, биты 3–0) |
| Синфазное напряжение | −0,3…48 В рабочее, 50 В предельное. **16,8 В — с большим запасом.** Напряжение шины меряется на IN− каждого канала, шаг 1,6 мВ |
| Питание | VS 1,7–5,5 В (EVM — 2,7–5,5 В), от 3V3 Pi |
| Адреса | 16 вариантов: A0 и A1 подключаются к GND, VS, SDA или SCL (табл. 6-1, 0x40–0x4F). На EVM задаются переключателями SW0/SW1. Сейчас 0x41: A1 = GND, A0 = VS. 0x40 занят PCA9685 |
| ALERT | Открытый сток, по умолчанию активен низким уровнем. Четыре регистра ALERT1–4 назначают каналу одну из функций: SOL/SUL (шунт выше/ниже предела), BOL/BUL (шина выше/ниже предела), POL (мощность). Сравнение идёт на каждом преобразовании, до усреднения, — быстрее данных. `ALERT_LATCH` держит сигнал, пока не прочитан FLAGS (0x22). На EVM ALERT подтянут 4,7 кОм и выведен на J2/J3 через буфер с открытым стоком SN74LVC1G07 |
| Шунты на EVM | По умолчанию не установлены: площадки 2512 (R12, R1, R13, R9), TI предлагает Ohmite PCS2512 10 мОм 2 Вт. **Менять можно.** Можно и подключить внешний шунт к клеммам IN+/IN− |
| Ток через EVM | **Не больше 10 А** через клеммы J1/J5 (предупреждение в SBOU298) |
| Минимальный CURRENT_LSB | I_max / 2¹⁵, допускается до 8× больше. SHUNT_CAL = 0,00512 / (CURRENT_LSB × R) |

### Назначение каналов

Предлагается иное, чем в `plans/pcb-rabbit-board.md`: канал 2 уже подключён к рейке 6 В, его оставляем как есть.

| Канал | Что | Шунт | Где | Диапазон | CURRENT_LSB / SHUNT_CAL | Рассеяние | Почему |
|---|---|---|---|---|---|---|---|
| 1 | батарея | **2 мОм**, внешний, четырёхвыводной (Kelvin), ≥ 1 Вт | после выключателя, до блока предохранителей | 41,0 А | 1,25 мА / 2048 | 0,39 Вт при 14 А | пик сумма ~10,4 А и предел площадки 14 А больше 10 А EVM, поэтому шунт вне EVM; запас ×2,7 к предохранителю 15 А, видны броски при включении; разрешение 1,25 мА при токе покоя ~2 А |
| 2 | руль 6 В | 10 мОм на EVM (как сейчас) | выход D36V50F6 | 8,19 А | 1 мА / 512 | 0,35 Вт на пике 5,9 А | пик 5,9 А = 59 мВ — помещается; сторона 6 В показывает просадку сервы (5,56 В) |
| 3 | моторы | **5 мОм**, внешний, Kelvin, ≥ 1 Вт | F1 → RoboClaw B+ | 16,4 А | 1 мА / 1024 | 0,18 Вт при 6 А, 0,5 Вт при 10 А | ограничение RoboClaw 2×3 А, предохранитель 10 А, запас ×1,6; в 2,5 раза точнее 2 мОм на типичных 0,03–0,5 А |
| 4 | Jetson 12 В | 10 мОм на EVM | выход D36V50F12 | 8,19 А | 1 мА / 512 | 0,03 Вт при 1,8 А | разъём Jetson ≤ 3,5 А; сторона 12 В показывает напряжение на разъёме (просадки, троттлинг из блога #132) |

**Почему не 2 мОм на обоих:** для моторов 41 А диапазона не нужны, а 5 мОм дают в 2,5 раза меньший шаг. Если удобнее купить одну позицию, 2 мОм на канале 3 тоже работают.

**Настройка ALERT:**

| Регистр | Канал | Функция | Порог |
|---|---|---|---|
| ALERT1 | 1 | BUL | 12,8 В (3,2 В/элемент) |
| ALERT2 | 1 | SOL | 13 А (26 мВ на 2 мОм) — близко к пределу площадки 14 А |
| ALERT3 | 3 | SOL | 8 А (40 мВ на 5 мОм) — моторы вышли за ограничение RoboClaw |
| ALERT4 | 4 | BUL | 11,0 В — преобразователь Jetson в ограничении |

Плюс `ALERT_LATCH = 1`. Реакции — в `-body.md`.

**Частота опроса.** Четыре канала по 2 × 588 мкс при усреднении 4 дают ~19 мс на круг. Это ~53 Гц на канал, публикация 50 Гц. Сейчас активны два канала, поэтому по каждому вдвое чаще.

### Риск в существующих данных

`node/ina.py` использует один `R_SHUNT = 0.01` для всех каналов. Если на канале 1 или 2 стоит не 10 мОм (владелец паял шунты сам), ток этого канала в Forge с 1 октября масштабирован неверно, в R_факт / 0,01 раз.

- **Что проверить:** маркировку на шунтах EVM. Например, `R010` — это 10 мОм, `R002` — 2 мОм. Или измерить мультиметром по четырёхпроводной схеме: ток 1 А, падение в мВ.
- **Изменение кода на потом** (сейчас не делаем: в коде узлов работают другие агенты):
  - `R_SHUNT` и `CURRENT_LSB` на канал;
  - запись `SHUNT_CAL` на канал;
  - имена каналов `battery`, `servo_6v`, `motors`, `jetson_12v`;
  - `ACTIVE_CHANNELS` = 4;
  - регистры ALERT;
  - флаг `clipped`, когда |шунт| > 0,95 диапазона.

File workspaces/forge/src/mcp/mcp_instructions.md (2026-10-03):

Forge holds telemetry from the Rabbit robot (drive motors, the 99 Wh 4S battery and power rails, steering, ZED camera IMU, magnetometer, barometer and pose, Jetson computer, Wi-Fi), every command sent to it with its sender, navigation and exploration state, configuration changes and the log records of all its nodes in ClickHouse, one run per recording session, on one clock.

Start with list_runs. For a question, search_slabs and run_slab first: slabs are reviewed queries whose columns carry units and measures (gauge values are averaged or taken as min or max, never summed over time; counter values are differences; event values sum; ratio values are recomputed, never averaged). Write SQL with query only when no slab fits; read describe_schema first. detect_anomalies flags unusual stretches of up to four related signals against a joint forecast that accounts for their covariates. metric_graph shows how metrics relate, and investigate walks it from a symptom to ranked causal chains with evidence, plus the commands, state transitions and logs around the focus. list_metrics catalogs every metric id with its table and NATS subject. timeline returns everything around a moment: commands, decisions (events with their reason and measured values), transitions, logs and a summary of every metric. The events table records every decision of the robot's nodes with its reason, ids (mission_id, trip_id, exploration_id, boot_id) and measured values; the decisions and nav_stops slabs read it. search_logs and logs_around read the robot's logs. ask answers a plain-language question end to end.

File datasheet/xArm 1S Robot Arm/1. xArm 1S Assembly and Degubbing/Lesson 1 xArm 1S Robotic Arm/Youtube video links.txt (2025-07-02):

xArm1S Robotic Arm Unboxing£ºhttps://youtu.be/GJZmPs0DtuA

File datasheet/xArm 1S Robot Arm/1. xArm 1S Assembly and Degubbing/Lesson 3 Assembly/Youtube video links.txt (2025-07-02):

xArm1S Robotic Arm Assembly 01: https://youtu.be/68N5oQAYfEI
xArm1S Robotic Arm Assembly 02: https://youtu.be/BhTdgkRTBoE
xArm1S Robotic Arm Assembly 03: https://youtu.be/ij0365iMALk

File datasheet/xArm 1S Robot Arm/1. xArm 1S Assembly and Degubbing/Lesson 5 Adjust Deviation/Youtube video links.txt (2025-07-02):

xArm 1S robotic arm small debugging after assembly£ºhttps://youtu.be/2Vt9rdCkfR8
xArm 1S Robotic Arm large debugging after assembly£ºhttps://youtu.be/7KJo6Jpx7v4

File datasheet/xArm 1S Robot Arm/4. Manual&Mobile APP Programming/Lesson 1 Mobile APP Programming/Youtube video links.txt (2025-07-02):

xArm 1S Robotic Arm Program with APP: https://youtu.be/8kBU3VoiAnQ

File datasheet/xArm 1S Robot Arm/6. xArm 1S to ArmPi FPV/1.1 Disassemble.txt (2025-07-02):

Video link: https://youtu.be/gw_UvgIpsPI

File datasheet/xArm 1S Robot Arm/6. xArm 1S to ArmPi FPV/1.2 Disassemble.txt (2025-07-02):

Video link: https://youtu.be/2TwcEvz1M54

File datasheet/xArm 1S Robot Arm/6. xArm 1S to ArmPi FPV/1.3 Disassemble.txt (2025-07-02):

Video link: https://youtu.be/vUPFuSscYF4

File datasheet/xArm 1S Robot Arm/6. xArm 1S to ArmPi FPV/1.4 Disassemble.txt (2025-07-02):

Video link: https://youtu.be/0FZN4LOGajQ

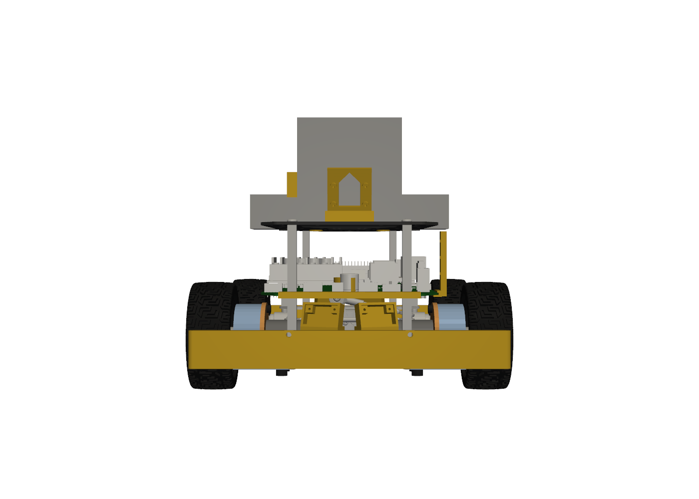
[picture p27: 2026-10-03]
cad/drive/renders/assembly_faulhaber_rear.png

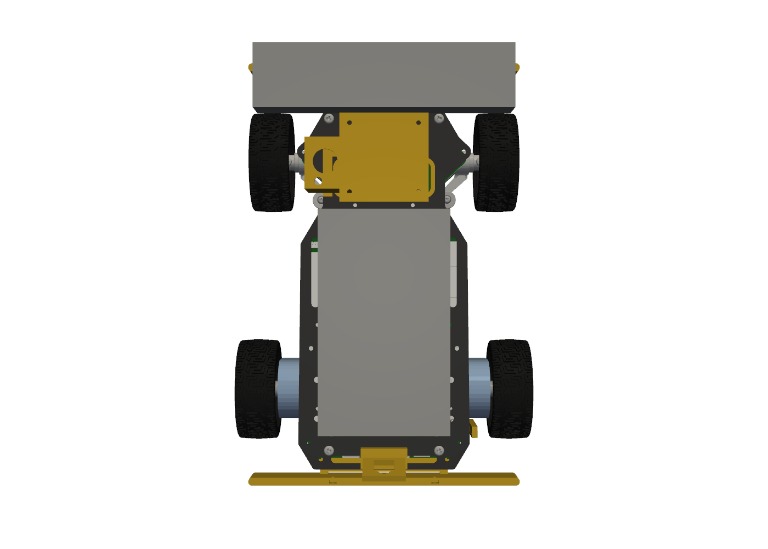
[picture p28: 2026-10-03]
cad/drive/renders/assembly_maxon_top.png

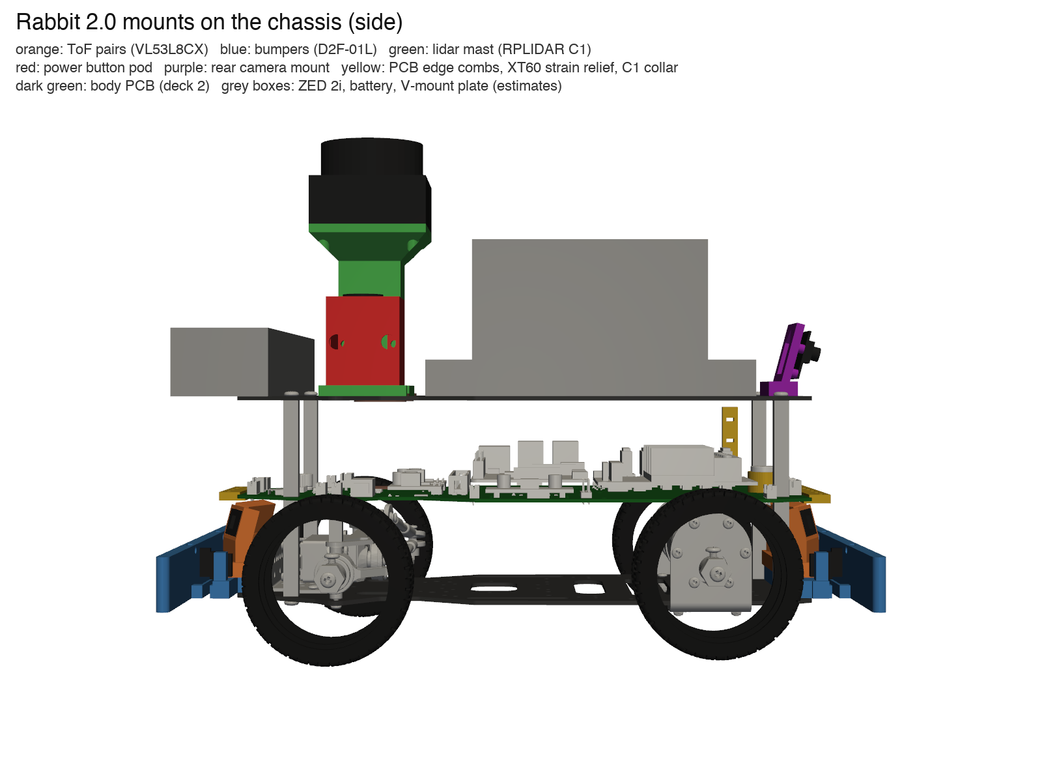
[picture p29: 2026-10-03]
cad/brackets/renders/assembly_side.png

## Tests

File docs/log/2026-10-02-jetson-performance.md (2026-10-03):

# Jetson performance tuning, the clock-floor incident and the upgrade assessment

Dates: 2026-10-01 09:10 UTC – 2026-10-02 22:45 UTC. Board: Jetson Orin Nano Super developer kit (p3767-0003), L4T R36.4.4 (JetPack 6.2.1), CUDA 12.6, TensorRT 10.3, Docker 27.5.1.

## Boot-time tuning (`workspaces/jetson/rabbit-performance`, `rabbit-performance.service`)

| When (UTC) | Change | Why |
|---|---|---|
| 2026-10-01 09:10 | `jetson_clocks`: CPU 1728 MHz × 6, GPU 1020 MHz, EMC 3199 MHz | under schedutil the CPU sat at 729.6 MHz and the ZED could not hold 30 fps (capture 34 ms vs 14.4 ms) |
| 2026-10-01 11:17 | oneshot service at boot: clocks, USB autosuspend off, Wi-Fi power save off | USB autosuspend (2 s) suspected in RoboClaw USB drop-outs; power save caused 1.5 s ping |
| 2026-10-01 11:17 | a first version ran `nvpmodel -m 0` assuming 0 = MAXN; on this board 0 is 15 W (2 = MAXN_SUPER). Reverted immediately | mode ids are board-specific: read `/etc/nvpmodel.conf` |
| 2026-10-02 00:02 | interrupts pinned: camera USB (xhci) → CPU2, RoboClaw UART → CPU4, I2C → CPU5 | every IRQ landed on CPU0, which ran at 100 %; after the change CPU0 32–59 %. The Wi-Fi interrupt (PCIe MSI) cannot be moved |
| 2026-10-02 00:02 | PCIe ASPM `performance`, `vm.swappiness=10` | Wi-Fi card on PCIe could sleep (unverified effect); about 1 GB was in swap |
| 2026-10-02 00:05 | headless: `multi-user.target`, GNOME and x11vnc off | about 300 MB RAM freed, swap 1005 → 551 MB |
| 2026-10-02 06:00 | UART IRQ pinned by device-tree hwirq | pinning by name in `/proc/interrupts` silently failed after every boot, because the serial port is not listed until it is opened |
| 2026-10-02 22:45 | `nvpmodel.service` drop-in (`workspaces/jetson/nvpmodel-rabbit.conf`: `RemainAfterExit=yes`, `ExecStartPost=/usr/bin/jetson_clocks`) | see the incident below |

Commit: `0b91121` (IRQs, ASPM, versioned script), `fd61834` (headless). The hwirq pinning and the drop-in are uncommitted at the time of writing.

## Incident: 85 minutes of low clocks (2026-10-02 00:06–01:30 UTC)

- Symptom in Forge: CPU at 730–1574 MHz, GPU 306–714 MHz for about 85 minutes; ZED capture fell from 29.6–30.0 to 26.5–28.5 fps. First attributed to over-current throttling.
- Root cause (power-throttling investigation, 2026-10-02 22:45 UTC): switching to headless ran `systemctl isolate multi-user.target` at 00:06:06. `nvpmodel.service` is a oneshot without `RemainAfterExit`, so `isolate` re-ran it and it restored the MAXN_SUPER default floors (CPU min 729.6 MHz, GPU min 306 MHz). `rabbit-performance` has `RemainAfterExit=yes`, stayed "active" and did not re-run. Evidence: Tj ≤ 58 °C, battery 15.6–16.7 V, power lower than before, and the floors exactly equal to the nvpmodel defaults. It ended with the next reboot.
- Fix: the drop-in above. Rule: never run `systemctl isolate` or `nvpmodel -m` on the live robot.

## OC3 events

`soctherm_oc` hwmon counts OC3 events: about 355,000 in 7.4 h of uptime at one point; 1–2/s typically, up to 28/s in another sample. OC3 is NVIDIA's throttle on instantaneous VDD_IN power (25 W threshold in MAXN_SUPER). Each event halves CPU/GPU clocks for about 1 ms; in total about 0.9 % of the time at half clock, about 0.5 % of performance. OC1 (under-voltage) and OC2 (average power) are 0; VDD_IN never below 4.936 V; no correlation with motor current (−0.03). NVIDIA describes OC in MAXN as expected and not to be disabled. Forge records the requested frequency, not the actual one, so it cannot see these dips (actual clocks and OC counters in telemetry are recommended, not done).

## Load picture

- Average power 10–12 W, peak 17.1 W; Tj max 60.6 °C; no thermal throttling.
- `rabbit-zed` dominates: p50 1977 MB / max 4651 MB RSS over 1–2 Oct before nvblox; 20–45 % CPU standing in localization mode, about 175 % driving, up to about 280 % exploring in mapping mode.
- The `uv run` wrappers of the nine Python nodes cost about 240 MB PSS; on 2026-10-02 23:09 UTC the compose commands became `uv sync --quiet && exec .venv/bin/python …`, and used RAM after a full deploy was 3.8 GB (was 4.4–6.4 GB).
- NVMe: 93 unsafe shutdowns out of 104 power cycles. The RTC does not keep time (likely no battery): the robot boots with a wrong clock and containers start before NTP, so Forge records the first seconds hours off. The journal is not persistent.

## JetPack upgrade assessment (2026-10-02 22:21–22:32 UTC)

- Don't upgrade now. The GPU is 20–25 % loaded; the bottlenecks are RAM and CPU, and none of the current problems (camera USB errors, SDK stalls, OC3, Wi-Fi) would be fixed.
- The apt cache held L4T 36.4.7 with a known CUDA regression; the `nvidia-l4t-*` packages were put on hold (50 packages held).
- From r36.5 UEFI enables DMA on `serial@3100000` (`/dev/ttyTHS1`, the RoboClaw UART) and zeroes the first bytes of each receive; on JetPack 7 / R39.2 on the Orin Nano Super the UART TX pin does not drive. Motor control would break without a device-tree overlay.
- Worth doing: Python 3.12 (with nvblox v0.0.10) on the current JetPack, estimated 1–3 days and 10–25 % less CPU for the Python nodes (Python 3.10 reaches end of life on 31 October 2026); JetPack 6.2.3 later for a boot-hang fix relevant to hard power-offs, after the UART workaround is tested on a stand; JetPack 7 not before 2027.

## Not done (recommended by the audit)

Remove snaps that update themselves on the live robot; prune about 77 GB of old Docker images (each `--build` deploy leaves an ~11 GB image); persistent journal; RTC battery; actual clocks and OC counters in Forge.

Reports: `docs/reports/2026-10-03-jetson-audit.md`, `docs/reports/2026-10-03-power-throttling.md`.

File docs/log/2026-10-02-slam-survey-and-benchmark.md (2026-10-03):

# SLAM survey and the localization benchmark (in progress)

Dates: survey 2026-10-02 22:15–22:27 UTC; benchmark from 2026-10-02 22:31 UTC, still running on 2026-10-03 00:20 UTC. Reports: `docs/reports/2026-10-03-slam-survey.md`, `docs/reports/localization-bench/results.md`. Bench tooling: `workspaces/bench/` (untracked).

## Question

"Are we reinventing the wheel?" after a day of relocalization failures.

## Survey verdict

- **Localization: yes.** `relocalization.py`, `JumpGate`, the millimetre filter, timeouts, `.area` archiving, map resets and the planner's relocalization gate all patch one black-box pose that serves as both odometry and global fix. ZED GEN_3 relocalizes through loop closure (the robot must revisit a known place), accumulates keyframes standing still, and GEN_1 in SDK 5.5 cannot relocalize from a `.area`.
- **Navigation: no.** Keep the own Hybrid A* (asymmetric curvature, camera-goal check, 30–80 ms on the Jetson), pure pursuit with the scan guard and blind-zone memory, frontier exploration and object viewpoints. Nav2's Smac planner supports one turning radius; MPPI for Ackermann has an open issue; Nav2 has no object viewpoints or blind-zone memory. Keep nvblox as a library.
- **Semantics:** YOLOE + object memory in ClickHouse + an LLM is close to OK-Robot/DynaMem; nothing ready-made exists for the Orin Nano.
- **Candidates:** cuVSLAM / PyCuVSLAM v17 (open source, aarch64 cp310 wheel, no ROS; odometry about 2 ms/frame; localization needs a prior pose, place recognition only in a draft PR) and RTAB-Map 0.23.8 (BSD, no ROS needed; bag-of-words global relocalization and multi-session maps; CPU, ~1 Hz). Rejected: ORB-SLAM3 (GPL, unmaintained), OpenVINS, VINS-Fusion, Kimera, Basalt, neural SLAM (too heavy next to the stack), Spectacular AI / Slamcore (paid on ARM, no ZED). Full ROS 2 + Isaac ROS + Nav2 reportedly does not fit in 8 GB.
- **Recommendation:** no ROS; ZED stays the camera and depth source; odometry from cuVSLAM or ZED VIO without area memory; global map and `map→odom` from RTAB-Map; nav in `odom`, planner and explore in `map`. Estimated to remove 400–700 lines of scaffolding. The `odom`/`map` split was done right away (`2026-10-02-odom-map-split.md`).
- **Switch criteria:** ≥ 90 % of wake-ups localized within 10 s and 1 m of travel, error ≤ 0.15 m at floor markers, zero false localizations beyond 0.5 m, total CPU not above GEN_3. Then a shadow run on the robot.

## Owner's mandate (22:29 UTC)

"Давай все перепишем… у тебя есть свобода экспериментировать… робот не в продакшене, мы можем ломать." The owner offered physical help: numbered tape crosses on the floor and placing the robot on them.

## Benchmark so far (results.md, 2026-10-02 23:46 UTC)

Two HD720 recordings with IMU: `loop1` (552 frames, 32.4 s, 3.91 m path) and `loop2` (1121 frames, 71.4 s, about 9 m). No ground truth yet: errors are against ZED VIO, so they measure consistency, not accuracy.

| Odometry | loop1 start–end gap | loop2 start–end gap | Tracker time p50 / p95 | RSS |
|---|---|---|---|---|
| ZED VIO | 0.67 m | 0.17 m | — | — |
| cuVSLAM stereo | 0.64 m | 0.19 m | 2.5 / 9 ms | about 255 MB |
| cuVSLAM inertial | 0.65 m | 0.32 m | 4.2 / 52 ms | about 290 MB |

All systems show the same 0.65 m gap on loop1, so the loop probably does not close in that recording.

| Localization | First match | Result |
|---|---|---|
| RTAB-Map, loop1 in the loop2 map | 2.6–4.3 s | 66–71 % of frames, 0 jumps > 0.5 m, 144–151 ms p50, ~1.3 cores, ~285 MB |
| ZED GEN_3, loop1 in loop2 | 6.7 s | 79 % |
| RTAB-Map, loop2 in the loop1 map | 0.5 s | 52–54 % |
| **ZED GEN_3, loop2 in loop1** | never | 0 % |
| RTAB-Map merge of both sessions | 0–1 s | 27–29 links between sessions, 0 jumps |
| RTAB-Map wake-up simulation (start every 5 s, 15 s window) | median 2.1 s / 5.8 s | 6/6 and 14/14 starts localized, 0 wrong; max 14 s |

RTAB-Map agrees with ZED's own relocalization to 0.015 m / 0.27°. RTAB-Map timings were measured on the Mac (arm64 container); Jetson timings are pending.

## Recordings for the next round

- `map-0930.svo2` (22:30 UTC, short: explore ended at "no reachable frontiers").
- `mapping-manual.svo2` (23:02 UTC, about 70 s): ended when `rabbit-zed` crashed with a CUDA out-of-memory in nvblox (RAM 6.2–6.5 of 7.4 GB).
- `mapping-manual2.svo2` (23:53–00:01 UTC, about 8 minutes, 2.6 GB), driven manually by the owner despite a Wi-Fi drop.

## Open at the time of writing

A GPU window with `rabbit-zed` stopped (from 2026-10-03 00:01 UTC) for cuVSLAM variants, cuVSLAM `localize_in_map` with RTAB-Map priors, RTAB-Map timing on the Jetson and depth modes (NEURAL_LIGHT, NEURAL FP16/INT8, NEURAL_PLUS); floor markers; wake-up sessions in different light; the integration itself.

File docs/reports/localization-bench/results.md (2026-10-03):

# Localization bench

Poses are in the IMAGE frame (x right, y down, z forward); plots are top-down (x, −z). cuVSLAM and ZED runs are on the Jetson; RTAB-Map runs are on the Mac (arm64 container) unless named `jetson_*`. CPU cores = CPU seconds per second (cuVSLAM: tracker only, per second of recording).

## loop1

### Odometry

| candidate | poses | path m | start–end m | start–end % | APE vs ZED VIO m | lost | ms p50 | ms p95 | CPU cores | RSS MB | GPU MB |
|---|---|---|---|---|---|---|---|---|---|---|---|
| ZED GEN_3 VIO (no area) | 552 | 3.91 | 0.67 | 17.0 | — | — | — | — | — | — | — |
| ZED GEN_3 with area memory (mapping) | 552 | 3.91 | 0.66 | 16.8 | 0.008 | — | — | — | — | — | — |
| cuVSLAM inertial_async | 552 | 3.91 | 0.65 | 16.8 | 0.028 | 0 | 4.2 | 8.6 | 0.08 | 298 | 350 |
| cuVSLAM inertial_slam | 552 | 3.90 | 0.65 | 16.5 | 0.029 | 0 | 4.5 | 73.0 | 0.19 | 324 | 393 |
| cuVSLAM inertial_slam (SLAM) | 552 | 3.90 | 0.65 | 16.5 | 0.029 | 0 | 4.5 | 73.0 | 0.19 | 324 | 393 |
| cuVSLAM inertial | 552 | 3.90 | 0.65 | 16.5 | 0.029 | 0 | 4.3 | 53.5 | 0.17 | 294 | 350 |
| cuVSLAM loc_in_loop2_blind | 552 | 3.90 | 0.65 | 16.5 | 0.029 | 0 | 4.4 | 61.8 | 0.19 | 333 | — |
| cuVSLAM loc_in_loop2_exact | 552 | 3.90 | 0.65 | 16.5 | 0.029 | 0 | 4.3 | 61.1 | 0.18 | 323 | — |
| cuVSLAM loc_in_loop2_noisier | 552 | 3.90 | 0.65 | 16.5 | 0.029 | 0 | 4.4 | 61.7 | 0.19 | 321 | — |
| cuVSLAM loc_in_loop2_noisy | 552 | 3.90 | 0.65 | 16.5 | 0.029 | 0 | 4.4 | 61.6 | 0.19 | 318 | — |
| cuVSLAM stereo_async | 552 | 3.91 | 0.64 | 16.4 | 0.016 | 0 | 2.5 | 6.8 | 0.03 | 263 | 350 |

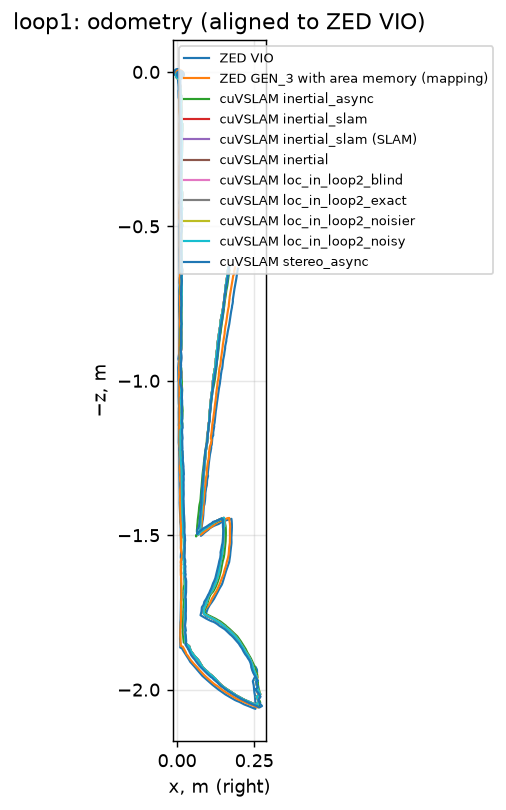
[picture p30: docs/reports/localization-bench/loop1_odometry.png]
odometry


### Localization

| candidate | mode | frames | first loc s | localized % | inter-session links | jumps >0.5 m | map→odom spread m | ms p50 | ms p95 | CPU cores | RSS MB |
|---|---|---|---|---|---|---|---|---|---|---|---|
| RTAB-Map loc_in_loop2_cuvslam_inertial | localization | 61 | 4.3 | 66 | 0 | 0 | 0.07 | 151 | 212 | 1.29 | 286 |
| RTAB-Map loc_in_loop2_cuvslam_stereo | localization | 61 | 2.6 | 71 | 0 | 0 | 0.08 | 144 | 198 | 1.32 | 283 |
| RTAB-Map loc_in_loop2_vio | localization | 61 | 2.6 | 70 | 0 | 0 | 0.08 | 149 | 210 | 1.29 | 284 |
| RTAB-Map loc_in_mapping-manual2_cuvslam_stereo | localization | 61 | 0.5 | 60 | 0 | 0 | 0.06 | 60 | 95 | 1.41 | 365 |
| RTAB-Map loc_in_mapping-manual2_vio | localization | 61 | 0.5 | 60 | 0 | 0 | 0.04 | 60 | 80 | 1.39 | 357 |
| RTAB-Map map_cuvslam_inertial | mapping | 61 | — | 0 | 0 | 0 | — | 61 | 71 | 1.27 | 236 |
| RTAB-Map map_cuvslam_stereo | mapping | 61 | — | 0 | 0 | 0 | — | 61 | 67 | 1.27 | 234 |
| RTAB-Map map_vio | mapping | 61 | — | 0 | 0 | 0 | — | 61 | 71 | 1.27 | 233 |
| RTAB-Map merge_into_mapping-manual2_cuvslam_stereo | mapping | 61 | 0.0 | 26 | 16 | 0 | 0.01 | 45 | 93 | 1.30 | 388 |
| RTAB-Map merge_into_mapping-manual2_vio | mapping | 61 | 0.0 | 31 | 19 | 0 | 0.01 | 43 | 83 | 1.30 | 382 |
| cuVSLAM loc_in_loop2_blind | localize_in_map | 552 | 0.5 | — | — | — | 1 attempts | 4.4 | 61.8 | 0.96 | 333 |
| cuVSLAM loc_in_loop2_exact | localize_in_map | 552 | 5.0 | — | — | — | 1 attempts | 4.3 | 61.1 | 0.95 | 323 |
| cuVSLAM loc_in_loop2_noisier | localize_in_map | 552 | 5.0 | — | — | — | 1 attempts | 4.4 | 61.7 | 0.96 | 321 |
| cuVSLAM loc_in_loop2_noisy | localize_in_map | 552 | 5.0 | — | — | — | 1 attempts | 4.4 | 61.6 | 0.95 | 318 |
| ZED GEN_3 zed_reloc_in_loop2 | area localization | 552 | 6.7 | 79 | — | 0 | — | 45 | 65 | — | — |
| ZED GEN_3 zed_reloc_in_mapping-manual2 | area localization | 552 | — | 0 | — | 0 | — | 45 | 66 | — | — |

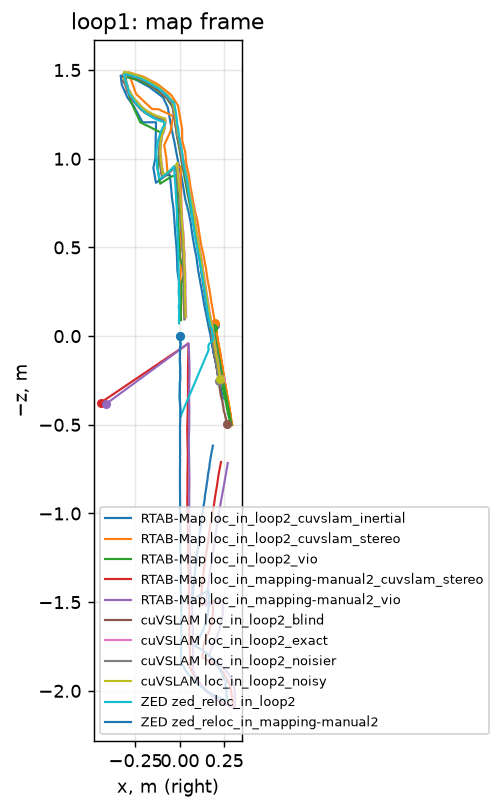
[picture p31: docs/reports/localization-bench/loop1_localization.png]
localization


## loop2

### Odometry

| candidate | poses | path m | start–end m | start–end % | APE vs ZED VIO m | lost | ms p50 | ms p95 | CPU cores | RSS MB | GPU MB |
|---|---|---|---|---|---|---|---|---|---|---|---|
| ZED GEN_3 VIO (no area) | 1121 | 8.78 | 0.17 | 1.9 | — | — | — | — | — | — | — |
| ZED GEN_3 with area memory (mapping) | 1121 | 9.06 | 0.21 | 2.3 | 0.048 | — | — | — | — | — | — |
| cuVSLAM inertial_async | 1121 | 9.01 | 0.32 | 3.5 | 0.079 | 0 | 4.4 | 9.1 | 0.07 | 293 | 350 |
| cuVSLAM inertial_slam | 1121 | 9.01 | 0.32 | 3.6 | 0.083 | 0 | 4.5 | 127.4 | 0.27 | 334 | 393 |
| cuVSLAM inertial_slam (SLAM) | 1121 | 9.12 | 0.20 | 2.2 | 0.042 | 0 | 4.5 | 127.4 | 0.27 | 334 | 393 |
| cuVSLAM inertial | 1121 | 9.01 | 0.32 | 3.6 | 0.083 | 0 | 4.4 | 56.2 | 0.19 | 279 | 350 |
| cuVSLAM loc_in_loop1_blind | 1121 | 9.01 | 0.32 | 3.6 | 0.083 | 0 | 4.2 | 89.4 | 0.30 | 339 | — |
| cuVSLAM loc_in_loop1_exact | 1121 | 9.01 | 0.32 | 3.6 | 0.083 | 0 | 4.3 | 87.1 | 0.29 | 336 | — |
| cuVSLAM loc_in_loop1_noisy | 1121 | 9.01 | 0.32 | 3.6 | 0.083 | 0 | 4.2 | 86.0 | 0.29 | 344 | — |
| cuVSLAM stereo_async | 1121 | 9.02 | 0.19 | 2.1 | 0.034 | 0 | 2.5 | 6.8 | 0.03 | 247 | 350 |
| cuVSLAM stereo | 1121 | 9.02 | 0.19 | 2.1 | 0.034 | 0 | 2.5 | 9.8 | 0.04 | 251 | 350 |

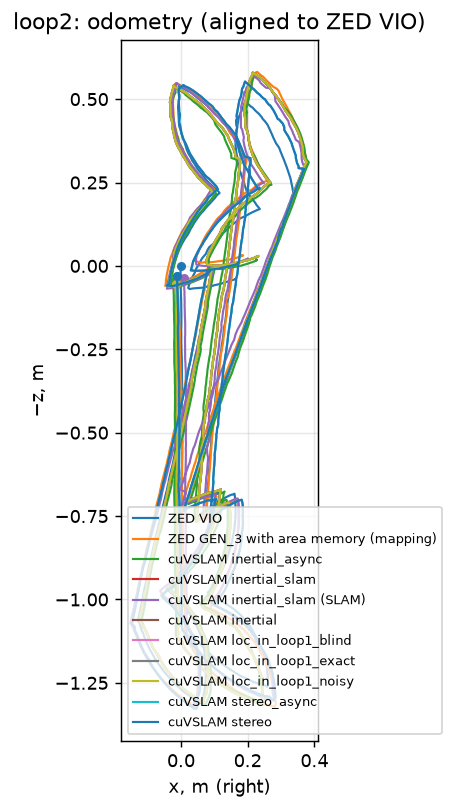
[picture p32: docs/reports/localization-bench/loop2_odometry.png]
odometry


### Localization

| candidate | mode | frames | first loc s | localized % | inter-session links | jumps >0.5 m | map→odom spread m | ms p50 | ms p95 | CPU cores | RSS MB |
|---|---|---|---|---|---|---|---|---|---|---|---|
| RTAB-Map jetson_loc_in_loop1_vio | localization | 135 | 0.5 | 51 | 0 | 0 | 0.13 | 195 | 228 | 1.04 | 220 |
| RTAB-Map jetson_map_vio | mapping | 135 | 35.5 | 66 | 0 | 0 | 0.09 | 109 | 217 | 1.08 | 277 |
| RTAB-Map loc_in_loop1_cuvslam_inertial | localization | 135 | 0.5 | 52 | 0 | 0 | 0.05 | 122 | 150 | 1.10 | 228 |
| RTAB-Map loc_in_loop1_cuvslam_stereo | localization | 135 | 0.5 | 54 | 0 | 0 | 0.05 | 118 | 139 | 1.10 | 225 |
| RTAB-Map loc_in_loop1_vio | localization | 135 | 0.5 | 54 | 0 | 0 | 0.09 | 122 | 150 | 1.10 | 226 |
| RTAB-Map loc_in_mapping-manual2_cuvslam_stereo | localization | 135 | 20.5 | 31 | 0 | 0 | 0.04 | 60 | 77 | 1.22 | 365 |
| RTAB-Map loc_in_mapping-manual2_vio | localization | 135 | 20.5 | 34 | 0 | 0 | 0.05 | 59 | 77 | 1.19 | 358 |
| RTAB-Map map_cuvslam_inertial | mapping | 135 | 26.9 | 51 | 0 | 0 | 0.23 | 66 | 148 | 1.18 | 279 |
| RTAB-Map map_cuvslam_stereo | mapping | 135 | 36.0 | 63 | 0 | 0 | 0.04 | 68 | 146 | 1.18 | 281 |
| RTAB-Map map_vio | mapping | 135 | 36.5 | 65 | 0 | 0 | 0.08 | 67 | 158 | 1.17 | 285 |
| RTAB-Map merge_into_loop1_cuvslam_inertial | mapping | 135 | 0.0 | 49 | 27 | 0 | 0.05 | 132 | 207 | 1.15 | 310 |
| RTAB-Map merge_into_loop1_cuvslam_stereo | mapping | 135 | 0.0 | 48 | 29 | 0 | 0.03 | 122 | 204 | 1.16 | 311 |
| RTAB-Map merge_into_loop1_vio | mapping | 135 | 1.0 | 50 | 28 | 0 | 0.07 | 130 | 213 | 1.16 | 310 |
| RTAB-Map merge_into_mapping-manual2_cuvslam_stereo | mapping | 135 | 19.9 | 58 | 14 | 0 | 0.04 | 48 | 97 | 1.18 | 440 |
| RTAB-Map merge_into_mapping-manual2_vio | mapping | 135 | 19.9 | 59 | 16 | 0 | 0.07 | 44 | 98 | 1.18 | 432 |
| cuVSLAM loc_in_loop1_blind | localize_in_map | 1121 | 21.6 | — | — | — | 8 attempts | 4.2 | 89.4 | 0.67 | 339 |
| cuVSLAM loc_in_loop1_exact | localize_in_map | 1121 | 21.5 | — | — | — | 11 attempts | 4.3 | 87.1 | 0.69 | 336 |
| cuVSLAM loc_in_loop1_noisy | localize_in_map | 1121 | 21.5 | — | — | — | 11 attempts | 4.2 | 86.0 | 0.73 | 344 |
| ZED GEN_3 zed_reloc_in_loop1 | area localization | 1121 | — | 0 | — | 0 | — | 47 | 70 | — | — |
| ZED GEN_3 zed_reloc_in_mapping-manual2 | area localization | 1121 | — | 0 | — | 0 | — | 47 | 64 | — | — |

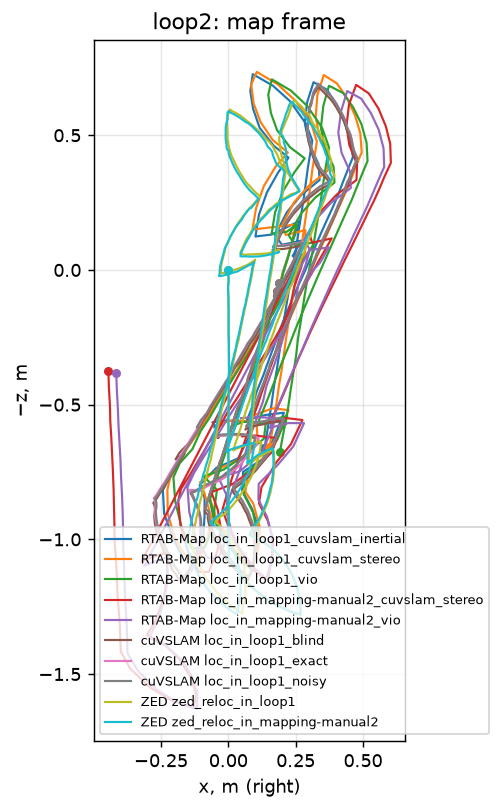
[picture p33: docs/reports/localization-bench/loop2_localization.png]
localization


## mapping-manual2

### Odometry

| candidate | poses | path m | start–end m | start–end % | APE vs ZED VIO m | lost | ms p50 | ms p95 | CPU cores | RSS MB | GPU MB |
|---|---|---|---|---|---|---|---|---|---|---|---|
| ZED GEN_3 VIO (no area) | 2098 | 24.59 | 0.75 | 3.1 | — | — | — | — | — | — | — |
| ZED GEN_3 with area memory (mapping) | 2098 | 26.05 | 1.05 | 4.0 | 0.212 | — | — | — | — | — | — |
| cuVSLAM inertial_slam | 2098 | 26.07 | 0.90 | 3.4 | 0.291 | 0 | 5.8 | 85.0 | 0.08 | 453 | — |
| cuVSLAM inertial_slam (SLAM) | 2098 | 26.59 | 0.57 | 2.2 | 0.255 | 0 | 5.8 | 85.0 | 0.08 | 453 | — |
| cuVSLAM inertial | 2098 | 26.07 | 0.90 | 3.4 | 0.291 | 0 | 4.9 | 53.8 | 0.07 | 295 | 350 |
| cuVSLAM stereo | 2098 | 25.03 | 0.48 | 1.9 | 0.173 | 0 | 2.6 | 16.9 | 0.01 | 250 | 350 |

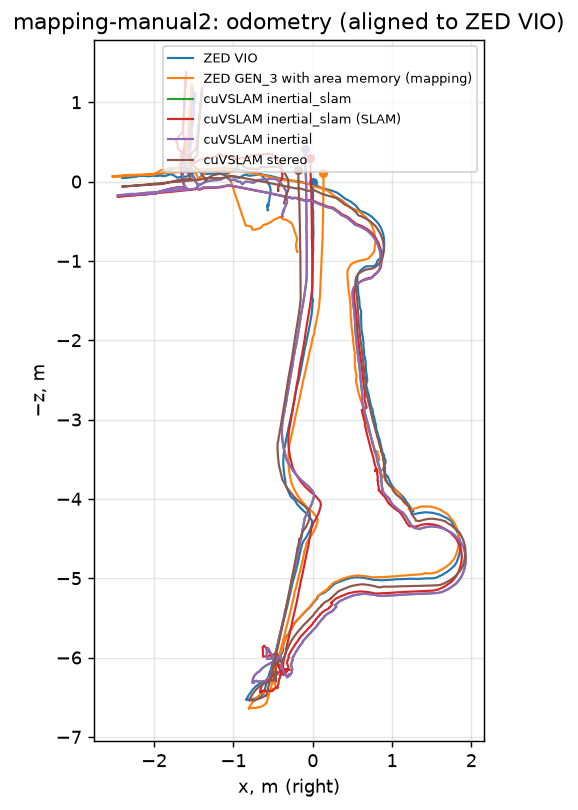
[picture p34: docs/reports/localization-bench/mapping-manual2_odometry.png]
odometry


### Localization

| candidate | mode | frames | first loc s | localized % | inter-session links | jumps >0.5 m | map→odom spread m | ms p50 | ms p95 | CPU cores | RSS MB |
|---|---|---|---|---|---|---|---|---|---|---|---|
| RTAB-Map map_cuvslam_stereo | mapping | 589 | 448.6 | 17 | 0 | 0 | 0.30 | 29 | 33 | 1.17 | 361 |
| RTAB-Map map_vio | mapping | 589 | 449.1 | 17 | 0 | 0 | 0.37 | 42 | 46 | 1.13 | 359 |

## ZED depth modes (loop1, HD720, depth at 640×360, robot runtime settings)

| mode | precision used | frames | open s | grab+retrieve ms p50 | p95 | GPU MB | valid % | floor σ mm @1/2/3/4/5 m | wall σ mm @1/2/3/4/5 m (noisy) | flying ‰ | temporal σ mm @1/2/3/4/5 m |
|---|---|---|---|---|---|---|---|---|---|---|---|
| neural fp16 | FP16 | 552 | 408 | 71.8 | 86.8 | 626 | 97.3 | 1 / 5 / 28 / 29 / 34 | 40 / 20 / 22 / 20 / 56 | 4.74 | 16 / 25 / 27 / 41 / 53 |
| neural int8 | FP16 | 552 | 710 | 69.6 | 84.6 | 709 | 98.4 | 1 / 5 / 12 / 21 / 29 | 37 / 32 / 21 / 25 / 46 | 10.84 | 12 / 28 / 33 / 59 / 69 |
| neural_light fp16 | FP16 | 552 | 2 | 63.3 | 83.8 | 191 | 97.5 | 1 / 6 / 19 / 23 / 28 | 24 / 29 / 38 / 23 / 58 | 6.17 | 16 / 25 / 36 / 62 / 62 |

`precision used` is what `get_init_parameters()` returns; for the INT8 run it says FP16, but the SDK log says `INT8 requested, INT8 in use` (separate `neural_depth_5.4` INT8 engine). `open s` includes the one-off TensorRT engine build. grab+retrieve includes lossless SVO decoding on the CPU. GPU MB is the nvmap peak of the container. Check the run log for other GPU work overlapping the timings.

## Wake-up simulation (RTAB-Map localization started every 5 s into the session, 15 s each)

Wrong = map←odom more than 0.3 m or 10° from the full-session reference. Per start: `offset s:first match s`.

| query in map | starts | localized | first match s median | max | wrong | per start |
|---|---|---|---|---|---|---|
| loop1 in loop2 (vio) | 6 | 6 | 2.1 | 7.0 | 0 | 0:2.6 5:1.6 10:1.0 15:7.0 20:1.6 25:4.4 |
| loop1 in mapping-manual2 (vio) | 6 | 5 | 0.5 | 3.1 | 1 | 0:0.5 5:0.5 10:0.5 15:0.6 20:3.1✗ 25:— |
| loop2 in loop1 (vio) | 14 | 14 | 5.8 | 14.0 | 0 | 0:0.5 5:0.5 10:9.7 15:5.3 20:1.1 25:7.3 30:2.2 35:1.1 40:14.0 45:9.1 50:7.5 55:11.3 60:6.4 65:2.0 |
| loop2 in mapping-manual2 (vio) | 14 | 10 | 1.6 | 13.9 | 0 | 0:— 5:— 10:10.2 15:5.3 20:0.6 25:0.5 30:0.5 35:— 40:— 45:13.9 50:5.5 55:0.5 60:0.5 65:2.6 |

## Cross-checks of map←odom (agreement between independent localizations)

| localization | compared with | difference |
|---|---|---|
| RTAB-Map loop1 in loop2 ∘ loop2 in loop1 (vio) | identity | 0.014 m / 1.32° |
| RTAB-Map loop1 in loop2 ∘ loop2 in loop1 (cuvslam_stereo) | identity | 0.039 m / 0.67° |
| RTAB-Map loop1 in loop2 ∘ loop2 in loop1 (cuvslam_inertial) | identity | 0.065 m / 3.05° |
| cuVSLAM loc_in_loop2_blind | RTAB-Map loop1 in loop2 (cuvslam_inertial) | 0.023 m / 2.95° |
| cuVSLAM loc_in_loop2_exact | RTAB-Map loop1 in loop2 (cuvslam_inertial) | 0.029 m / 2.95° |
| cuVSLAM loc_in_loop2_noisier | RTAB-Map loop1 in loop2 (cuvslam_inertial) | 0.010 m / 3.13° |
| cuVSLAM loc_in_loop2_noisy | RTAB-Map loop1 in loop2 (cuvslam_inertial) | 0.025 m / 3.02° |
| cuVSLAM loc_in_loop1_blind | RTAB-Map loop2 in loop1 (cuvslam_inertial) | 0.032 m / 0.72° |
| cuVSLAM loc_in_loop1_exact | RTAB-Map loop2 in loop1 (cuvslam_inertial) | 0.021 m / 0.69° |
| cuVSLAM loc_in_loop1_noisy | RTAB-Map loop2 in loop1 (cuvslam_inertial) | 0.022 m / 0.69° |
| RTAB-Map loop1 in loop2 (vio) | ZED GEN_3 loop1 in loop2 | 0.015 m / 0.27° |

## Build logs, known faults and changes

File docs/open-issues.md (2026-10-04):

# Открытые вопросы и проблемы

Единый список всего, что ждёт решения: вопросы владельцу, нерешённые проблемы, проверки, для которых нужен робот. Держать актуальным (правило в `AGENTS.md`):
- нашёл вопрос или проблему — добавь строку со следующим номером и ссылкой на источник;
- получил ответ или решил — перенеси в «Закрыто» с датой и ответом;
- подробности живут в `docs/reports/` и `docs/log/`, здесь только суть и ссылка.

Обновлено: 2026-10-03.

## Вопросы владельцу

| # | Вопрос | Зачем | Источник |
|---|---|---|---|
| Q1 | Стойки палуба 1 → плата: можно 45 мм? Измерить нынешние линейкой (по фото ~40 мм) | Над вентилятором Jetson при 40 мм остаётся 2–3 мм | `reports/2026-10-03-body-pcb.md` §3, §12 |
| Q2 | Кулер Pi не выше 35 мм над Pi (ICE Tower не влезет): какой ставим? | Высота между платой и палубой 3 | body-pcb §12 |
| Q3 | 5 В к Pi по 40-жильному шлейфу (падение ~65 мВ при 2 А) — устраивает? | Иначе два провода AWG20 | body-pcb §12 |
| Q5 | Левый мотор завести на M2 RoboClaw (при клеммах назад M1 справа)? | Порядок каналов в `roboclaw.py` | body-pcb §12 |
| Q7 | Сейчас Jetson питается от своей понижайки, от общей с моторами или прямо от батареи? | Возможная причина перезагрузки 1 октября посреди манёвра | `log/2026-10-03-power-rails.md` |
| Q8 | Провод от площадки V-Mount: сечение? Стоит ли ещё в цепи XY-CD63L? | Сечение входа платы, отсечка разряда | `reports/2026-10-03-architecture-2.0.md` |
| Q9 | Кнопка питания: двухполюсная 16 мм с подсветкой подходит? Нужна ли отдельная утопленная кнопка жёсткого выключения на случай зависшего Pi? | Схема питания, панель кнопки | architecture-2.0 |
| Q10 | Как резолвится `jetson.rabbit` — DNS роутера или `/etc/hosts`? | HUD переезжает на Pi | architecture-2.0 |
| Q11 | Паять батарейку RTC на Jetson (J3, SMD 0402) или хватит времени с Pi? | Часы после выключения | architecture-2.0 |
| Q12 | Начинать этап 0 (ограничение тока RoboClaw, энкодеры), пока едут детали? | Порядок работ | `log/2026-10-03-phase-0-tools.md` |
| Q13 | Антенны Wi-Fi Alfa (~19 см) пересекают плоскость скана лидара (теперь 230 мм): короткие антенны (верх ниже 220 мм), наклон или маска секторов? | Тени в скане | `reports/2026-10-03-mounts.md` |
| Q14 | ToF на 57,8 мм над полом наклонены на 15° вверх (пол с ~0,44 м): низкие предметы ближе ~0,4 м видит только бампер. Устраивает? | Компромисс отражений от пола | mounts |
| Q19 | Своя прошивка FOC (SimpleFOC на STM32G474 + DRV8316, переносится на плату) или готовые ODrive Micro / moteus c1 с CAN-HAT на Pi? | Прототип и плата rev B | `reports/2026-10-03-bldc-drive.md` §5.3, §9 |
| Q20 | Можно выпилить в палубе 1 окно ~14 × 24 мм под каждым мотором (кромки паза y 83, x 8…32 мм от центра), если понадобится запасной Faulhaber 3216 (корпус Ø32 заходит в палубу на 0,67 мм)? С maxon не нужно | Запасной мотор | `reports/2026-10-03-bldc-drive.md` §13.2 |
| Q23 | Шлейф задней камеры: через задний край палубы 3 (крепления так рассчитаны)? Паз y 51 из отчёта о плате закрыт площадкой V-Mount | Путь шлейфа CSI | `reports/2026-10-03-mounts.md` |
| Q24 | Полярность XT60 и XT30 на плате: «+» на выводе 1 (сторона со скосами) — сверить с «+» на литье разъёма до пайки, провод батареи прозвонить | Даташит Amass полярность не рисует | `reports/2026-10-03-body-pcb-review.md` N7 |
| Q25 | Размер литой вилки USB-A кабеля ZED: пройдёт ли в вырез платы 11,1 × 18 мм (был 7,8 × 13,8)? Втулку `cad/brackets/zed_grommet.py` пересчитать на новый вырез | Кабель ZED к Jetson сквозь плату | body-pcb-review S6 |
| Q28 | Поведение safety и rabbit-power там, где `-body.md` молчит (выбрано и закреплено тестами): после удара бампером ползти от препятствия ≤ 0,1 м/с, а если бампер всё ещё нажат после 0,5 м — стоп (оборванный провод не должен увозить робота вслепую); «50 % скорости» при низкой батарее — команда делится пополам; при молчащем мозге отвергаются только команды с `source: nav`; автоматический перезапуск Jetson по питанию — только из RUNNING, как на схеме (не загрузившийся Jetson — вручную `power_cycle_jetson`). Подтвердить или поправить | Поведение защиты и питания | `log/2026-10-03-body-software.md` |
| Q29 | Адрес Pi в домашней сети для деплоя: оставить имя `rabbit-body.local` (`RABBIT_BODY_HOST`) или фиксированный IP? | `scripts/deploy.sh --body` | `log/2026-10-03-body-software.md` |
| Q32 | Запасной выход в rev B: хватит ли J49 (шина моторов, F2 10 А) вместо отдельной ветви F7/J20 rev A? Под что выход (бывший Q6)? | Номинал и место ветви | `reports/2026-10-03-body-pcb-rev-b.md` §14 |
| Q33 | Жёсткое выключение кнопкой при зависшем Pi (долгое нажатие → OFF в железе) — добавить в rev C? Сейчас только вынуть XT60 | Q9 | body-pcb-rev-b §3.1 |
| Q36 | В предпросмотре JLC проверить повороты и первый вывод U1 (LQFP-64), U4/U6 (RPH), U10 (DRR), U11/U12 (RGF), Q1/Q2/Q6 (DFN5x6), U5 (HTSSOP), J45/J46 | CPL без поправок под библиотеку JLC | body-pcb-rev-b §14 |
| Q38 | Предохранители rev B — SMD NANO2 2410 (15/10/5/5 А): сгоревший меняется паяльником, не рукой, как ATO. Устраивает, или F1 вернуть в держатель ATO (ручная пайка)? | Обслуживание; бывший Q4 | body-pcb-rev-b §1, §14 |
| Q40 | Заказываем 2 (+1 запасной) × maxon ECX FLAT 22 L 18 В + GPX 22 LN 16:1 + ENX 22 MILE (код B845D2FFA4A0, €429,78 за шт., maxon Australia), детали ЧПУ из `cad/drive/` (JLCCNC/PCBWay, ~US$200–260), 4 × SKF 61803-2RS1 и стенд DRV8316REVM + NUCLEO-G474RE? Сначала — печатная примерка и замеры M13–M18 | Привод; ~A$2 000–2 200 | `reports/2026-10-03-bldc-drive.md` §13.8, `cad/drive/README.md` |

## Измерить на роботе

| # | Что | Принято сейчас | Для чего |
|---|---|---|---|
| M1 | Длины стоек палуба 1 → плата → палуба 3 (измерить две линейкой) | 45 + 45 мм: плата 69,8 мм, палуба 3 сверху 118,4 мм над полом; крепления пересчитаны на это | Плата, высота мачты лидара (`cad/brackets/common.py`) |
| M2 | Верх батареи вместе с площадкой V-Mount | ~192 мм (площадка ~17 мм по фото 03.10) | Должен быть ниже основания лидара (200,2 мм, плоскость скана 230 мм) |
| M3 | Задняя грань ZED с вилкой USB и передний край площадки V-Mount на палубе 3, от переднего края палубы | по фото 03.10: 23 и 90 мм; площадка кончается в 25 мм от заднего края | Мачта стоит в полосе 40–81 мм, задняя камера — в последних 15,5 мм |
| M4 | Максимальный угол поворота колёс | ±40° | Зазор до бамперов |
| M6 | Габарит хаба Waveshare USB 3.2 | по чертежу Waveshare 72,2 × 47,8 × 27,6 мм (86 мм с ушками), порты на обеих длинных сторонах; место — см. P14 | Место под палубой 3 |
| M7 | Купленная кнопка: длина корпуса за панелью, гайка | ≤ 37 мм, ≤ 21 мм | Панель кнопки |
| M8 | Где реально стоит ZED относительно задней оси | код: 0,1845 м (`CAMERA_TO_REAR_AXLE`); по фото 03.10 ZED у самого носа палубы 3, объектив ~0,24 м | `CAMERA_TO_REAR_AXLE` и место мачты лидара |
| M9 | Перед пайкой: распиновка D24V90F5 и Pololu #2813 по шелкографии модулей | выведена из чертежей; ревью сверило с подписями на изометрии Pololu — совпадает (`reports/2026-10-03-body-pcb-review.md` §1) | Плата rev A |
| M11 | Шум привода сейчас: телефон со спектром в 30 см от задней оси, 0,16 / 0,3 / 0,5 м/с, колёса в воздухе и на полу; дБ(A) и частота самого громкого тона | замеров нет | Эталон для сравнения с 19:1 и BLDC (`reports/2026-10-03-bldc-drive.md` §10) |
| M12 | Выводы THT под носом и хвостом платы (J8, J9, J13, J6, J7, J11, J14) после пайки | обрезать до 1,5 мм | Головки ToF на 2,7 мм ниже самых длинных выводов (`reports/2026-10-03-mounts.md`) |
| M13 | Как сейчас закреплены расширенные кронштейны моторов; расстояние от отверстий M4 палубы 1 (в модели 46,4 мм от центра) до внутренней грани кронштейна | 142 мм между гранями → 71 мм от центра, лапа нового кронштейна на штатных отверстиях | `cad/drive/geometry.py` `HALF_GAP`, `FOOT_HOLES` |
| M14 | Высота оси заднего колеса над верхом палубы 1; кромка палубы от центра | 15,3 мм; 60,3 мм (модель кита) | Зазор мотора до палубы, `AXLE_Z`, `PLATE_EDGE` |
| M15 | Заднее колесо: от внутренней грани кронштейна до внутреннего торца обода и до дна шестигранного гнезда; свободный диаметр в ступице колеса | 8,8 и 17,9 мм; Ø12 (как штатный хаб) | Полуось и корпус подшипников, `WHEEL_INNER`, `HEX_FACE` |
| M16 | Что есть под палубой 1 у задних углов (зона лапы 40 × 30 мм) и у кромки палубы над задней осью | свободно | Лапа кронштейна под палубой |
| M17 | Контур платы Холлов maxon ECX FLAT 22 L по STEP из конфигуратора (B845D2FFA4A0, «Create CAD data») | ≤ R17, ставится вверх | Зазор до палубы 1 и платы, `MOTORS["maxon"]["tab"]` |
| M18 | Колея задних колёс после расширения (между центрами) | 188,8 мм; колёса на 7 мм шире бамперов | `Footprint` в `lib/safety.py` (половина ширины) |

## Нерешённые проблемы

| # | Проблема | Статус | Источник |
|---|---|---|---|
| P1 | Wi-Fi в дальней комнате: −74 дБм, роутер отключает робота (reason 34) | Решение в 2.0: USB-адаптер с внешней антенной; дешевле — вторая точка доступа | `log/2026-10-03-field-session.md` |
| P2 | ZED GEN_3: миллиметровые позы после перелокализации, зависания `grab()` на 2–4 с, долгая перелокализация после переноса | Обойдено фильтрами; замена — rabbit-loc (RTAB-Map), ждёт робота для теневого режима | `log/2026-10-03-rabbit-loc.md` |
| P3 | Энкодеры не считают (подключены неправильно) | Скрипт проверки готов, нужна перепайка | phase-0 |
| P4 | Понижайка 12 В моторов на пределе (11,3 В при ~4,1 А) | В 2.0 RoboClaw от батареи с ограничением 3 А/канал | power-rails |
| P7 | Forge всё ещё на ClickHouse | Переход по runbook ждёт робота; удалять ClickHouse — только с согласия владельца | `reports/2026-10-03-forge-cutover-runbook.md` |
| P8 | Команда 94 RoboClaw (запись в NVM): руководство и библиотека расходятся | Инструмент пробует оба варианта; проверить на роботе | phase-0 |
| P9 | После установки бамперов габарит робота меняется | Обновить `Footprint` в `lib/safety.py` и `front_overhang` в `lib/planner.py` | mounts |
| P10 | Детектор плохо находит холодильник | Оценить классы и пороги на сохранённых кадрах (нужен `detector.onnx` с робота) | roadmap |
| P11 | Магнитометр не откалиброван | Не используется; калибровать, если понадобится | roadmap |
| P12 | Python 3.12 для образа робота | Патч готов, применить вместе с пересборкой образа | `reports/2026-10-03-python312.md` |
| P13 | Мотор и контроллер вместо 37D 70:1 + RoboClaw | BLDC выбран (C25): **maxon ECX FLAT 22 L 18 В + GPX 22 LN 16:1 + ENX 22 MILE**, новый кронштейн с двумя подшипниками и муфтой Oldham (`cad/drive/`), плата rev B без изменений (переходные кабели, §13.6). Ждёт замеров M13–M18, печатной примерки и заказа (Q40) | `reports/2026-10-03-bldc-drive.md` §13, `log/2026-10-03-bldc-drive-mount.md` |
| P17 | Ядро Raspberry Pi (rpi-6.6, rpi-6.12) по умолчанию оставляет выход GPIO в последнем состоянии после смерти процесса (`pinctrl_bcm2835.persist_gpio_outputs=Y`, коммит `d61c12f36d8d`): упавший `rabbit-safety` оставил бы ESTOP_RUN высоким. Предпосылка `-body.md` и `-wiring.md` «ядро отпускает линию» на ядрах Raspberry Pi неверна | `scripts/body-setup.sh` ставит `persist_gpio_outputs=n` в `cmdline.txt`; safety не поднимает линию, если параметр `Y`; следующий уровень — нулевая команда roboclaw через 0,4 с без `rabbit.safety.drive`. Проверить на Pi (V7) | `log/2026-10-03-body-software.md` |
| P18 | Python-драйвер VL53L8CX (`circuitpython-vl53lxcx` 0.0.5) с тремя ошибками: путь к прошивке, порядок байтовых массивов (зона i лежит в i XOR 3), опрос без пауз | Обёрнут в `lib/tof_device.py` (smbus2, без Blinka). Порядок зон, поворот платы (roll 90°) и «перпендикулярное» расстояние выведены из документации ST — проверить на датчике (V9); если не заработает, порт C-драйвера ST (STSW-IMG040) | `log/2026-10-03-body-software.md` |
| P19 | Системный загрузчик STM32G47x на USART2 PA2/PA3 (прошивка MCU с Pi через `stm32flash`) не перепроверен по свежей AN2606 | Проверить до заказа платы rev B (бывший Q35); иначе прошивка только по SWD (J47) | body-pcb-rev-b §4, §14 |
| P20 | Rev B: агенту CAD обновить `cad/brackets/` — гребёнка заднего края (фазы JST VH, Холлы PH, энкодеры GH), клипса XT60 рядом с J11, убрать `cap_clamp` и кронштейн хаба USB, перегенерировать сборку с новым `rabbit-body.step` (бывший Q37) | Механика под rev B | body-pcb-rev-b §9 |
| P21 | Плата rev B: VREF обоих DRV8316 без своего 0,1 мкФ у вывода (опора — 1 мкФ на AVDD через ~8 мм дорожки по In2; 0,1 мкФ не поместился между выводами SPI/CSA с шагом 0,5 мм) | На стенде проверить шум нуля усилителей тока; если мешает — rev C, 0201 у вывода 37 | `reports/2026-10-03-body-pcb-rev-b.md` §4 |
| P22 | Плата rev B: 5 В Холлов и энкодеров (J43–J46) через 10 Ом 0805 — при КЗ в кабеле резистор перегорает | rev C: ограничитель тока TPS2553 (C55266) на сторону | `reports/2026-10-03-body-pcb-rev-b.md` §4 |
| P23 | Плата rev B не закончена: агент остановлен владельцем 2026-10-04 посреди ручной разводки (сеть обратной связи понижающих преобразователей, кластер DRV8316); последнее состояние — коммит `eb7deb0`, отчёт `docs/reports/2026-10-03-body-pcb-rev-b.md` может быть неполным. Продолжить: доразвести, DRC, сравнить fastroute и Freerouting, проверить §8 отчёта BLDC (maxon, Холлы + ENX 5 В) | На паузе | `pcb/rabbit-body/gen/` |

## Проверить на роботе (после деплоя)

Порядок и команды — в `docs/roadmap.md` и `scripts/bringup.py`.

| # | Что |
|---|---|
| V1 | Офлайн-работа 2–3 октября: трекер, исследование (новый «доделать комнату»), сброс одометрии, тесты nvblox |
| V2 | События наблюдаемости rabbit-zed и rabbit-telemetry (ни разу не запускались), таблица `nats_server`, реальная нагрузка проб на Jetson |
| V3 | Этап 0: `roboclaw_config.py read/plan/apply`, 3 А сохраняются после выключения, `power.calibrated`, `duty_max = 1` |
| V4 | Переход Forge на Parquet + chDB по runbook |
| V5 | Записи для бенчмарка локализации (≥ 14 fps), затем rabbit-loc в теневом режиме |
| V6 | Диета Jetson (`diet.sh --dry-run`, потом по-настоящему), пересоздать rabbit-telemetry |
| V7 | Pi: `cat /sys/module/pinctrl_bcm2835/parameters/persist_gpio_outputs` = N; самопроверка safety проходит (бит E-stop 0x1 в статусе RoboClaw при S3 «E-Stop» без защёлки); колёса в воздухе, `docker kill rabbit-safety` — флаг E-stop и стоп ≤ 0,1 с |
| V8 | Лидар C1: `lidar.connected` с `sample_hz` 5000 в режиме SCAN, `lidar_health` 10 ± 0,5 Гц, ≥ 450 точек, `bad_nodes` 0 за минуту; стена спереди — в секторе 0 (знак yaw, P16); задержка UART в `LIDAR_LATENCY_MS`; устройство UART4 для `LIDAR_PORT` |
| V9 | ToF: все четыре инициализируются на i2c-3…6 (≤ ~2,2 с, растягивание такта BCM2711), 4 × 15 Гц в `tof_health`; закрыть рукой один угол датчика — точки в том же углу (`TOF_FLIP_*`, `TOF_ROLL_DEG`); стена в 0,3 м даёт 0,3 м; пол точек не даёт |
| V10 | Образ `rabbit-body`: руль через Blinka на I2C1, `rabbit-ina` с `I2C_BUS=1`, roboclaw на `/dev/ttyAMA0`; `rabbit-power` из venv хоста видит кнопку и светодиоды |
| V11 | Safety на Pi: CPU и `step_ms` в `node_metrics` (на Mac 2,3 % ядра и 0,17 мс), бампер → нулевая команда ≤ 50 мс, откат на стену коробки 0,15 м/с — стоп в 0,05–0,12 м, 10 из 10 (этап 3) |
| V12 | `rabbit-power`: долгое нажатие — выключение ≤ 90 с, Jetson останавливается сам (агент `rabbit-jetson-power`), короткое — мигание заряда; `power_cycle_jetson` по запросу |

## Закрыто

| # | Вопрос | Ответ | Дата |
|---|---|---|---|
| C1 | Pi 4 какой памяти? | 8 ГБ | 2026-10-03 |
| C2 | Шунты на INA4235EVM | R010 = 10 мОм, токи в Forge с 1 октября верны | 2026-10-03 |
| C3 | RoboClaw по UART или USB? | UART основной, USB запасной | 2026-10-03 |
| C4 | Этажи корпуса | 3 этажа: металл (моторы, Jetson) / плата тела / металл (батарея, ZED, лидар) | 2026-10-03 |
| C5 | 4G (Teltonika TRB246) | Пока убран из 2.0 | 2026-10-03 |
| C6 | Как подключена батарея | Через площадку V-Mount; пластина уже закреплена на палубе 3 | 2026-10-03 |
| C7 | Почему в блоге осталась одна запись | Скрипт добавления постов 187–188 открывал файл на запись до чтения и стирал старые посты. Восстановлено из git, в скилл `rabbit-blog` добавлена проверка числа постов | 2026-10-03 |
| C8 | Коммитить незакоммиченную работу? | Да: всё закоммичено и запушено 2026-10-03 (5 коммитов + блог) | 2026-10-03 |
| C9 | Перенести блог в репозиторий rabbit | Перенесён с историей в `workspaces/blog`, публикация `scripts/blog.sh publish` | 2026-10-03 |
| C10 | Блог на GitHub Pages с доменом | `.github/workflows/blog.yml` собирает и деплоит `workspaces/blog`; DNS rabbit0.dev → CNAME `seralexeev.github.io` (DNS only), сертификат GitHub, Enforce HTTPS; проекты Cloudflare Pages удалены, репозиторий rabbit0 в архиве | 2026-10-03 |
| C11 | P16: поворот лидара C1 в README креплений | Исправлено: кабель вперёд, yaw 180° (как в `rabbit-lidar` по умолчанию); знак проверить по первому скану (V8) | 2026-10-03 |
| C12 | Q17: Привод: сначала Pololu 37D 19:1 #4751 на RoboClaw (сразу ~1,5 м/с, US$140), а BLDC параллельно на столе — или сразу BLDC? | Сразу BLDC, без промежуточного Pololu 19:1 (ответ владельца). План — `reports/2026-10-03-bldc-drive.md` §6 | 2026-10-03 |
| C13 | Q18: Передаточное число: 1,5 м/с вручную (18,8–19:1) или запас момента на пороги (30:1, ~1,1 м/с)? | Снят ответом на Q21: редуктор 6,25:1 (~2,3 м/с под нагрузкой), 10:1 — запасной | 2026-10-03 |
| C14 | Q21: Какой круиз нужен в автономе после 2.0 (лидар, энкодеры, EKF): 0,5 или 0,8 м/с? | «Не гоночная машина и не медленный робот — хочу потенциал ехать быстро»: 1,5 м/с — минимум, рассматривать 2–2,5 м/с, круиз в софте. Выбран 6,25:1 (`reports/2026-10-03-bldc-drive.md` §6.1) | 2026-10-03 |
| C15 | Q22: У батареи NEEWER есть отдельный зарядный вход? Принимает ли она ток назад через площадку V-mount? | Исследовано: по спецификации NEEWER площадка и D-Tap — входы 16,8 В до 8 А («Fully charged in 3h via a 16.8V D Tap charger»), т. е. заряд принимает. Поведение BMS на полном заряде и при бросках не опубликовано → проектируем как «не принимает»: ток назад ≤ 0,5 А в прошивке, тормозной ключ 17,6 В, идеальный диод не нужен (`reports/2026-10-03-bldc-drive.md` §7) | 2026-10-03 |
| C16 | M10: свободная длина под мотор | Шасси расширено: между кронштейнами 142 мм, ~70 мм на мотор (владелец); модель кита (58 мм) устарела. Нынешний 37Dx70L помещается, Pololu 37Dx68L — тоже | 2026-10-03 |
| C17 | Q27: Заводская сборка: все THT отдать JLC? Модули Pololu заменить своими преобразователями и eFuse в rev B? | Да (решение владельца). Rev B: 2 × LM61495, LM74800 + 2 × NCEP4090GU вместо #2813, TPS16630 для Jetson, NANO2 вместо ATO; JLC ставит все 95 строк, включая THT; руками на плате ничего (`reports/2026-10-03-body-pcb-rev-b.md` §10) | 2026-10-03 |
| C18 | P14: хаб USB Waveshare не помещается | Хаб не нужен: RoboClaw ушёл, Pi 4 хватает своих портов (флешка + Wi-Fi Alfa, ~1 А из ~1,2 А); J19/F6 убраны в rev B (body-pcb-rev-b §9) | 2026-10-03 |
| C19 | P15, P6: PCA9685PW 0 шт., INA4235 1 шт. | Склад JLC ≠ витрина LCSC: PCA9685PW у JLC 393 шт. (+1 205 Q900); INA4235 заменён на 4 × INA226 (44 033 шт.). Все 95 строк rev B есть у JLC минимум на 3 комплекта (`pcb/rabbit-body/fab/rabbit-body-revB-stock.csv`) | 2026-10-03 |
| C20 | P5: ALERT INA не подключён | Rev B: ALERT всех четырёх INA226 на GPIO24 (открытый сток, 10 кОм); пороги в регистрах 06/07 — правка `ina.py` | 2026-10-03 |
| C21 | Q6: резервная ветка F7/J20 — под что? | В rev B ветви нет (не помещается рядом с VBUS без пересечения питания моторов); запасной выход — J49 от шины моторов. Вопрос продолжен в Q32 | 2026-10-03 |
| C22 | Q26: 1 кОм S3→GND у RoboClaw и провод сквозь #2813 | Неактуально в rev B: RoboClaw и #2813 нет; ESTOP тянется к земле 10 кОм на плате. Для отката на RoboClaw через J48 — 1 кОм к GND в разъёме по-прежнему нужен | 2026-10-03 |
| C23 | Q4: предохранители меняются только со снятой палубой 3 | Rev B: держателей ATO нет, предохранители NANO2 впаяны; вопрос заменён Q38 | 2026-10-03 |
| C24 | M5: какая версия моторов 37D | **Pololu #4754** «70:1 Metal Gearmotor 37Dx70L mm 12V with 64 CPR Encoder (Helical Pinion)», 4 480 отсчётов на оборот колеса (владелец) | 2026-10-03 |
| C24 | Q34: NCEP4090GU (Wuxi NCE) как главный и тормозной ключ | Снят правилом владельца «деньги не ограничение, качество»: в rev B Infineon BSC010N04LS (Q1, Q2) и BSC026N04LS (Q6) | 2026-10-03 |
| C25 | Q39: щёточный Pololu #4751 «как есть» или BLDC с новым кронштейном | **BLDC выбран владельцем.** Мотор — maxon ECX FLAT 22 L 18 В + GPX 22 LN 16:1 + ENX 22 MILE (Ø22, помещается над палубой 1; Faulhaber 3216 — запасной), кронштейн 6061 с двумя SKF 61803-2RS1 и муфтой Oldham, печатный вариант для примерки (`cad/drive/`, `reports/2026-10-03-bldc-drive.md` §13) | 2026-10-03 |
| C26 | Q30, Q31: заказ Pololu #4751 и режим «быстро» 14 В | Сняты выбором BLDC (C25); заказ — Q40 | 2026-10-03 |

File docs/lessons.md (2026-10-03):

# Lessons

Short rules learned the hard way on this robot, each with the reason. Details are in `log/`.

## Robot and camera

- **Never attach gdb to `rabbit-zed`.** A ptrace attach froze the camera for about 2 minutes and the process stayed stopped after the tool timed out; gdb in a container on the Jetson hung over 10 minutes loading CUDA/TensorRT symbols. Use `py-spy dump --nonblocking` and `top -H`.
- **Don't run `systemctl isolate` or `nvpmodel -m` on the live robot.** `isolate` re-ran `nvpmodel.service`, which reset the `jetson_clocks` floors: 85 minutes of low clocks that looked like over-current throttling.
- **nvpmodel ids are board-specific.** `-m 0` is 15 W on this Orin Nano; MAXN_SUPER is 2.
- **Check the clocks before blaming code.** Under schedutil the CPU sat at 730 of 1728 MHz and the camera could not hold 30 fps.
- **Pin IRQs by device-tree hwirq, not by name.** The UART is not in `/proc/interrupts` until it is opened, so name-based pinning silently did nothing after every boot.
- **An area file saved while LOST breaks relocalization.** Save the SDK area map only when localized and in mapping mode; never save a failed session over a good map.
- **Count relocalization only after a localized status holds for 10 s.** The SDK reports KNOWN_MAP, re-initialises 5–8 s later, and LOST is not relocalized.
- **Sanity-check every SDK pose.** For a few seconds after relocalizing GEN_3 returns millimetres instead of metres; those poses corrupted a map and produced kilometre "jumps".
- **Base give-up rules on distance travelled, not time or `camera_moving_state`.** The SDK says MOVING while the robot stands still; timers discarded good maps.
- **Restart the camera process after a tracking failure; don't re-enable tracking in-process.** Re-enabling left the SDK broken and produced poses tens of metres away.
- **Don't switch to localization in front of a blank wall.** It stayed INITIALIZING for over an hour; switch only with an open view and after being localized for a while.
- **GEN_3 lifelong mapping leaks keyframes in SDK 5.5.0.** CPU grows on a standing robot; localize by default, map only for new areas.
- **Don't cap the ZED compute fps to save CPU.** It saved nothing and added about 55 ms of pose latency.
- **Keep heavy native calls out of the camera loop.** The mesh filter held the GIL for up to 2 s; pyzed calls hold the GIL, so per-update work must scale with what changed.
- **Long SDK initialisation (TensorRT engine build, 9 minutes) belongs in a thread.** On the event loop it missed NATS heartbeats and restarted the container.
- **Copy GPU images to the host before indexing them in C++.** Reading the ESDF slice from device memory segfaulted.
- **Do a full ESDF update after loading a map.** Incremental updates ignore loaded blocks and the grid came out empty.
- **Guard the map against pose jumps.** Skip integration above 1.5 m/s, clear blocks beyond 50 m, window the grid; debris 1.5 km away made a message too big to publish.
- **Integrate periodically while static.** Otherwise a freshly reset map stays empty.
- **Stop distances must be outside the depth blind zone, and blind-zone memory must not expire.** At 0.15 m with 4 s memory the robot drove into a wall; at the same time a stuck phantom point must be released eventually (about 30 s).
- **Use the k-th nearest point per scan sector.** Single flying pixels near the lens stopped the robot.
- **Measure obstacle height from a per-frame floor plane.** 1° of tilt is 5 cm at 3 m; the floor was reported as contact.
- **A floor estimate must not follow the robot onto a table.** Adopt a new level only after driving on it.
- **Track Ackermann paths by the rear axle.** Tracking the camera point 0.18 m ahead made reverse drift sideways.
- **Calibrate curvature per side and use the same tables everywhere.** Left and right turns differ (servo neutral).
- **IMU bump thresholds need margin over normal start jerk.** Launch jerk reached 3.49 m/s² against a 3.5 threshold.
- **Benchmark on a recorded SVO, on a stationary robot, with nothing else running.** Live numbers were contaminated by driving from the public HUD and by other sessions.
- **Separate odometry from the global fix.** With nav on `odom`, map corrections no longer jerk the steering.

## Hardware and OS

- **Use `/dev/serial/by-id/...` for USB serial, and catch `termios.error`.** ttyACM numbers change after a replug or reboot.
- **Turn off Wi-Fi power save in the NetworkManager connection itself.** The Realtek driver re-enabled it after each reconnect; global settings did not stick.
- **The rtl88x2ce driver ignores the country code.** Power comes from its limit table.
- **Make Wi-Fi changes with an automatic rollback.** Wi-Fi is the robot's only link.
- **Take device timestamps through an offset to the system clock.** After an NTP step at boot the camera clock was 5.7 minutes behind.
- **The RTC does not keep time and the board is often powered off hard.** Expect wrong timestamps right after boot.
- **Fit printed parts to the robot, not to `model/chassis.step`.** The kit model has 50 mm standoffs and two decks; the robot has three (deck 1, the body PCB, deck 3 on 45 + 45 mm), so deck 3 is ~42 mm higher and the PCB hangs ~3 mm over the ToF heads. The owner's V-mount plate is twice as long as assumed. `cad/brackets/assembly.py` rebuilds the stack with the PCB STEP and boxes for the ZED, V-mount plate and battery; check against a current photo too.
- **Fill KiCad zones with `kicad-cli pcb drc --refill-zones --save-board`, not the Python `ZONE_FILLER`.** From a standalone script the filler ignored hole and board-edge clearances (`log/2026-10-03-body-pcb.md`).
- **On a Raspberry Pi a GPIO output outlives the process that drove it.** Raspberry Pi kernels 6.6 and 6.12 set `pinctrl_bcm2835.persist_gpio_outputs` to true, so a crashed process leaves the pin at its last level; a fail-safe "held high while alive" line needs `pinctrl_bcm2835.persist_gpio_outputs=n` on the kernel command line, a check of `/sys/module/pinctrl_bcm2835/parameters/persist_gpio_outputs` before raising it, and a `docker kill` test on the real board (`log/2026-10-03-body-software.md`).
- **Read a lidar's zero angle from its datasheet, not from where the cable goes.** The RPLIDAR C1's 0° is opposite the cable; mounted cable-forward its scan is turned by 180°.
- **Export the DSN for Freerouting without full-board fills and run it with `-mt 1`.** KiCad exports every zone as a plane that blocks the layer; the multi-threaded optimiser adds clearance violations. It is deterministic: when a net stays unrouted, change the input (placement, widths, keepouts), re-running does nothing. Inner cut-outs need a keepout, the DSN does not carry them.

## Software and data

- **Never use a bare `except:` in async node code.** It swallowed `CancelledError`, nodes never shut down and the map was never saved.
- **Never call blocking libraries on the asyncio loop.** One `jtop.ok()` gave a node a 2.4 s NATS RTT.
- **Publish JSON with `allow_nan=False`.** Python writes `NaN`, which browsers reject.
- **Don't write hardware-read values back into persistent KV as defaults.** It froze white balance at 4000 K.
- **Fixed-point wire formats need a per-chunk origin.** int16 millimetres overflowed when the pose ran away to −138 m.
- **Set explicit NATS pings on long-lived clients and tolerate reconnects on publish.** The default 2-minute ping hid dead links for minutes; a NATS restart crashed a node.
- **A recorder must validate rows and retry only connection errors.** One bad timestamp blocked a table for 8 minutes.
- **Batch ClickHouse inserts on a small host.** Parts and merges, not rows, cost the CPU (1 s → 10 s flushes cut it in half).
- **Raise the request body limit in front of a chat that resends its history** (413 on long chats).
- **AI SDK tool approvals need the approval response to be the last message.** A system reminder appended after it meant approved missions never ran.
- **Approval decisions come from code, not the model.** Spoken approval is parsed from the operator's own short utterance; negation wins.
- **Give the agent local time and the UTC offset from code**, keep data in UTC.
- **Open-vocabulary detectors need per-class thresholds and track confirmation**, and the HUD must merge by class and position, not by SDK id.
- **Record the reason with every stop, not only the stop.** Nav's `free_distance = 0` meant an obstacle, a blind camera, a stale scan or a stale pose, and a stale pose stopped the robot without a trace; "why did it stop" was unanswerable from data. Nav now records `nav.hold` and `nav.safety_stop` with the reason and the measurement behind it.
- **One missing field drops the whole message in Forge.** The full-stack simulator's pose, motor, telemetry and camera-health messages lacked fields Forge requires, so sim runs recorded none of them, silently except for the writer's `malformed` counter. Make new fields optional, and check `malformed` after every sim run.

## Deploying and working with agents

- **Never run a plain `vite build` in `workspaces/web`.** `dist/` ships on every deploy; a default build broke the public HUD with CORS errors. Check with `tsc`.
- **Deploy with force-recreate; `docker compose restart` keeps the old image.**
- **Mount code, bake only dependencies, and keep a `.dockerignore` next to data.** Deploys went from over 10 minutes to about 30 s.
- **Any deploy rsyncs the whole tree and starts stopped services.** Coordinate with other sessions and don't deploy during a benchmark window.
- **Start servers the owner relies on with `nohup`.** Agent background tasks die after 2 hours.
- **Export the data before switching the robot off for offline work.** The overnight forensics needed the Parquet export.
- **Check new DNS names only against a public resolver.** The home router cached NXDOMAIN for 30 minutes.
- **Use HTTP/2 for the Cloudflare tunnel.** QUIC connections stayed stuck after a Wi-Fi drop.
- **Serve `index.html` with `no-cache`.** Browsers kept an old HUD after deploys.
- **Focus the HUD chat input by reference before typing in browser automation.** Single-letter hotkeys arm GO TO.
- **No motion without the owner's go-ahead in the session**, and stop at once when told the robot is not on the floor.
- **Far floor needs range-aware handling in the depth kernel.** At 4–5 m a 1° pose pitch error lifts the floor ~7 cm, above the 4 cm obstacle band; on 2026-10-03 integration to 5 m filled the clearance grid with phantom obstacles ("obstacles where the robot stands"). `depth.cu` now drops near-floor points beyond 2 m (3 cm + 2 cm/m of range); keep that before raising `MAX_INTEGRATION_DISTANCE` further.
- **IMU bump detection needs averaging.** With `SENSOR_PUBLISH_S = 0.01` each IMU message carries ~1 sample and floor vibration reaches 8–10 m/s², tripping the 5 m/s² collision threshold; nav now averages 50 ms.
- **Motor current alone can't detect a stall at low duty.** Reversing into an unseen wall at 17% duty draws 0.5–0.7 A, far below the 1.8 A stall threshold; nav also trips `stuck` when it commands motion and the pose hasn't moved for 2.5 s.
- **Back up only over trail the robot drove forward, and check it against the map.** A trail of positions taken in reverse order crosses gear changes; deriving headings from it flipped them by 180° and moved the camera points 0.37 m off the trail. 10 of 15 recoveries were malformed, one reversed into a wall that was in the map and one ran blind for 4.3 m. Keep the trail in the odometry frame, drop it when the robot is lifted, and cap every recovery in time and distance.
- **Don't plan a manoeuvre for a goal the robot already meets.** A viewpoint 7 cm away and 22.5° off produced a 2.2 m loop, 198 times; finish such trips at once.
- **Send the planned heading with every path point.** The heading derived from neighbouring camera points is off by up to ~23° on tight arcs (the camera sits ahead of the rear axle), so the rear-axle path was 3–5 cm off and any tracker followed it with a steady error.
- **The IMU can't see slow contacts.** At ~0.1 m/s a contact peaks at 1.7–2.5 m/s², inside floor vibration (50 ms mean, max 4.5); only pose-based `stuck` and current-based `stall` catch them.
- **A generated KiCad board inherits the old project file.** `pcbnew.NewBoard` reads the existing `.kicad_pro`, so net class patterns from earlier runs pile up and a width change in the generator silently loses to a stale class; clear classes and patterns before defining them (`pcb/rabbit-body/gen/build_board.py`).
- **Budget low-voltage sensor rails by path resistance, not by net class.** The rev A body board fed four ToF carriers (VIN ≥ 3.2 V) from a 3.3 V LDO over 0.4 mm tracks on a 0.5 oz inner layer: 0.72 Ω to the far connector. Compute the path, keep supply runs off thin inner copper.
- **Check LCSC stock for every assembled part before calling a board ready.** On the review day PCA9685PW had 0 and INA4235 1 in stock, which blocks JLC assembly regardless of the design.
- **Ask JLC's assembly stock, not the LCSC shop page, and check the model it returns.** PCA9685PW showed 0 at LCSC but 393 in JLC's assembly stock; `pcb/rabbit-body/gen/stock.py` queries JLC for every number and caught six LCSC codes in my own tables that pointed at other values.
- **The TVS clamp voltage, not the battery voltage, sets the ratings of everything behind it.** SMBJ20A clamps at 32.4 V, which rules out 28–30 V bucks, eFuses and FETs on a 16.8 V pack.
- **Dimensions in parentheses on TI land patterns are centre-to-centre.** Reading them as outer extents put the DRV8316 and LM74800 pads onto their exposed pads; DRC caught it as shorts.
- **Freerouting needs the power pours as filled copper plus keepouts.** KiCad exports a zone to the DSN as a plane by its outline, which swallows the pads of other nets inside it (they stay unrouted), and a plane on a signal layer is no obstacle to Freerouting, so it routes straight through pours and the refill splits them. `pcb/rabbit-body/gen/autoroute.py` writes each pour's filled copper as the plane and the same copper shrunk by 0.35 mm as a keepout.
- **Overlapping KiCad zones of one net but different priority don't connect.** The lower one is knocked out with the zone clearance; merge each net's pour polygons per layer into one zone (`pcb/rabbit-body/gen/routing.py`).
- **Freerouting doesn't route a pad to a plane on a signal layer.** Hand-route every pad-to-pour connection (or give the pour net a track the router can reach).
- **Don't edit a shell script while it runs.** `sh` reads the file as it goes; editing `make.sh` mid-run made it execute a fragment of a line and skip the cleanup and DRC steps.
- **A coaxial wheel motor is limited by the deck, not the length budget.** On Rabbit the rear axle is only 15.3 mm above deck 1, so any body wider than Ø30 coaxial with the wheel hits it (the Faulhaber 3216's Ø32 by 0.67 mm). Check the radius to the deck before the length.
- **Don't hang a wheel on a small gearhead shaft; nest the coupling to save length.** The rated radial load is quoted 10 mm from the flange, and the wheel centre is 30–40 mm out. Carry the wheel on bracket bearings, and put an Oldham coupling inside a hollow stub axle around the gearhead shaft: stacking the coupling behind the bearings cost ~10 mm, which pushed the two motors past the centreline (`cad/drive/`).

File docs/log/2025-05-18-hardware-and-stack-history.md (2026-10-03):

# Hardware and software stack history (May 2025 – October 2026)

Period: 2025-05-18 to 2026-10-01. Sources: the public build log at https://rabbit0.dev (posts 1–163, 18-05-2025 to 30-08-2025), the git history of this repo, and what the agent sessions found on the robot on 2026-10-01.

## Context

Rabbit is a small rover on an RC car kit with Ackermann steering. The goal from the start was a robot driven over the internet, and then autonomous navigation.

## Hardware as of October 2026

| Part | What |
|---|---|
| Chassis | RC car kit with Ackermann steering; aluminium steering hubs and metal ball links replaced the plastic parts (blog #101, #93) |
| Compute | NVIDIA Jetson Orin Nano Super developer kit, 8 GB (7.4 GB usable), 6 cores, NVMe 915 GB, L4T R36.4.4 (JetPack 6), power mode MAXN_SUPER |
| Camera | ZED 2i, 2.1 mm lenses (serial 31819002, firmware 1523), on USB. Depth from about 0.3 m only, so there is a blind zone in front of the bumper |
| Drive | 2 × Pololu 37D 70:1 12 V gear motors at the rear, 37Dx70L with 64 CPR encoders, helical pinion (#4754, 4480 counts per wheel revolution; confirmed by the owner 2026-10-03; the old whiteboard says 37Dx54L, which is wrong), RoboClaw 2x30A (firmware USB Roboclaw 2x30a v4.3.6). The wheel encoders do not count (always 0), so speed comes from the camera pose |
| Steering | brushless servo (A50BHL) on a PCA9685 (I2C bus 7, address 0x40), 1000–2000 µs, centre trimmed to 1532 µs |
| Power | 99 Wh V-mount 4S Li-ion pack (16.8 V full, 14.8 V nominal) with its own BMS; buck converters for 12 V (RoboClaw), 6 V (servo) and the Jetson input; INA4235 4-channel monitor at I2C 0x41 with 10 mΩ shunts (channel 1 battery, channel 2 the 6 V rail; channels 3–4 unwired) |
| Network | Wi-Fi only: Realtek rtl88x2ce PCIe card (`wlP1p1s0`) |
| Geometry | wheelbase 0.1715 m, rear track 0.1674 m, 75 mm wheels; camera 0.137 m above the floor, 0.1845 m ahead of the rear axle and 0.06 m off the centreline; mass about 3.5 kg |

Not installed: the robot arm, the 4G/5G gateway and a lidar (all mentioned in the blog as plans). `model/` holds a CAD model of the chassis and `pcb/rabbit-board` a KiCad power/I-O board that exists only as a design (commit `b88c33b`, pushed 2026-10-01).

## Timeline

| Date | Change | Source |
|---|---|---|
| 2025-05-18 | Project start on a Raspberry Pi 4 with a PCA9685 for the servo | blog #1–4 |
| 2025-05-21 | RoboClaw does not stop when the controlling script dies; RC timeout and a command loop are needed | blog #6 |
| 2025-05-22 | Motors run over UART; a TXB0104 level shifter did not work for the 5 V RoboClaw RX | blog #7–8 |
| 2025-05-25 | First drive; Python script with joystick and RoboClaw threads; Docker Compose + uv | blog #29, #37, #40 |
| 2025-06-04 | Jetson Orin Nano Super chosen; flashing L4T to NVMe took several attempts with the SDK Manager | blog #70–75 |
| 2025-06-17 | WebRTC streaming and data channel control | blog #82 |
| 2025-07-03 – 07-07 | About a week on ROS 2 (git: `ros2_ws`, `rabbit-ros2`, foxglove bridge), then removed in favour of NATS (`cd31f6d nats`, `35794ec drop ros2`, 2025-07-04) | blog #115–121 |
| 2025-07-16 | ZED 2i arrives; streamed over NATS | blog #123 |
| 2025-07-18 | Jetson reports "System throttled due to over-current"; suspected voltage drop on a thin AWG22 barrel lead | blog #132 |
| 2025-07-21 | Drives on battery with remote control and 720p30 video | blog #148 |
| 2025-07-22 | No hardware H.264 encoder on the Orin Nano; camera work collapsed into one process | blog #150–152 |
| 2025-08-08 | NATS JetStream KV for camera settings | blog #158 |
| 2025-08-16 | First nvblox integration (nvblox_torch, torch 2.3.0 built for the Jetson, separate `rabbit-nvblox` container fed RGB+depth over NATS) | blog #160–162, git `abaf00c`…`abb35ef` |
| 2025-08-30 | Electronic differential calibrated | blog #163 |
| 2026-01-31 – 2026-04-09 | "wip" commits; the robot copy gained `node/perception.py`, `lib/occupancy.py` and `node/telemetry.py` | git |
| ~2026-05 | All containers stopped; the robot stayed off for about five months | `docker ps` on 2026-10-01 |
| 2026-10-01 | `b88c33b` pushes the chassis model, the PCB design and the robot-side perception node; the agent sessions start (see the following log entries) | git |

## Stack decisions that still hold

- **NATS instead of ROS 2.** Every node is a container running one Python file; messages are JSON or small binary formats on NATS subjects, with JetStream for the KV bucket `rabbit` and the `LOGS` stream. The reasons given in the blog (#117–119): ROS 2 build tooling (colcon, ament, CMake, package.xml) was too heavy for a one-person project, and a plain bus lets nodes be written in any language.
- **One camera process.** Only one process can open the ZED, and the Orin Nano has no hardware video encoder, so `rabbit-zed` owns the camera and does tracking, depth, mapping, obstacle scan, detection and preview.
- **Docker Compose on the robot** (`workspaces/compose.yaml`), code bind-mounted, deployed from the Mac with `scripts/deploy.sh`.

## State found on 2026-10-01

- `/root/rabbit` on the robot is not a git checkout; code arrives by rsync. Until the push of `b88c33b` the robot was ahead of GitHub.
- Published topics were few and slow: `rabbit.roboclaw` 10 Hz (speed and encoder only), `rabbit.ina` 1 Hz, `rabbit.telemetry` 1 Hz, `rabbit.sensor.bundle` (RGB+depth, 13.5 Hz, about 5.5 MB/s), a JSON costmap at 2 Hz (235 KB/s).
- About 75 GB of old Docker images (nvblox, WebRTC, test images) were left on the NVMe.

See `2026-10-01-revival-and-telemetry.md` for what changed next.

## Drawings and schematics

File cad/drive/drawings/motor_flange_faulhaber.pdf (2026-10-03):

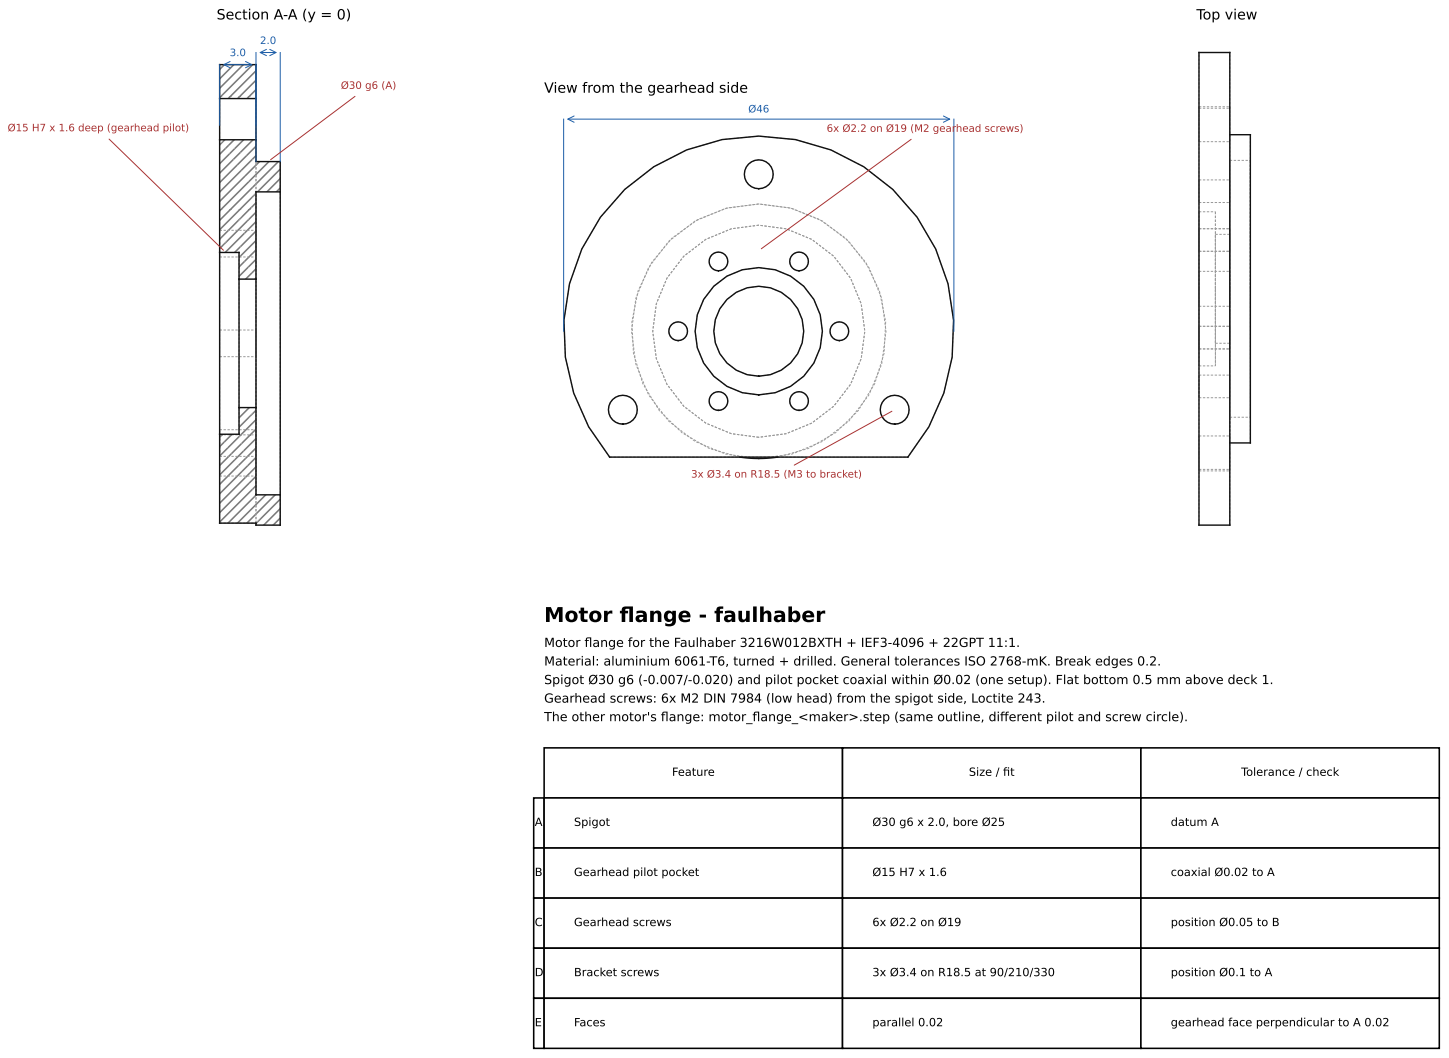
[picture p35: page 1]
Section A-A (y = 0); Top view; Feature; Size / fit; Tolerance / check; Spigot; Ø30 g6 x 2.0, bore Ø25; datum A; Gearhead pilot pocket; coaxial Ø0.02 to A; Gearhead screws; position Ø0.05 to B; Bracket screws; position Ø0.1 to A; Faces; parallel 0.02; gearhead face perpendicular to A 0.02

View from the gearhead side

Ø15 H7 x 1.6 deep (gearhead pilot)

6x Ø2.2 on Ø19 (M2 gearhead screws)

3x Ø3.4 on R18.5 (M3 to bracket)

Motor flange - faulhaber

Motor flange for the Faulhaber 3216W012BXTH + IEF3-4096 + 22GPT 11:1.

Material: aluminium 6061-T6, turned + drilled. General tolerances ISO 2768-mK. Break edges 0.2.
Spigot Ø30 g6 (-0.007/-0.020) and pilot pocket coaxial within Ø0.02 (one setup). Flat bottom 0.5 mm above deck 1.
Gearhead screws: 6x M2 DIN 7984 (low head) from the spigot side, Loctite 243.
The other motor's flange: motor_flange_<maker>.step (same outline, different pilot and screw circle).

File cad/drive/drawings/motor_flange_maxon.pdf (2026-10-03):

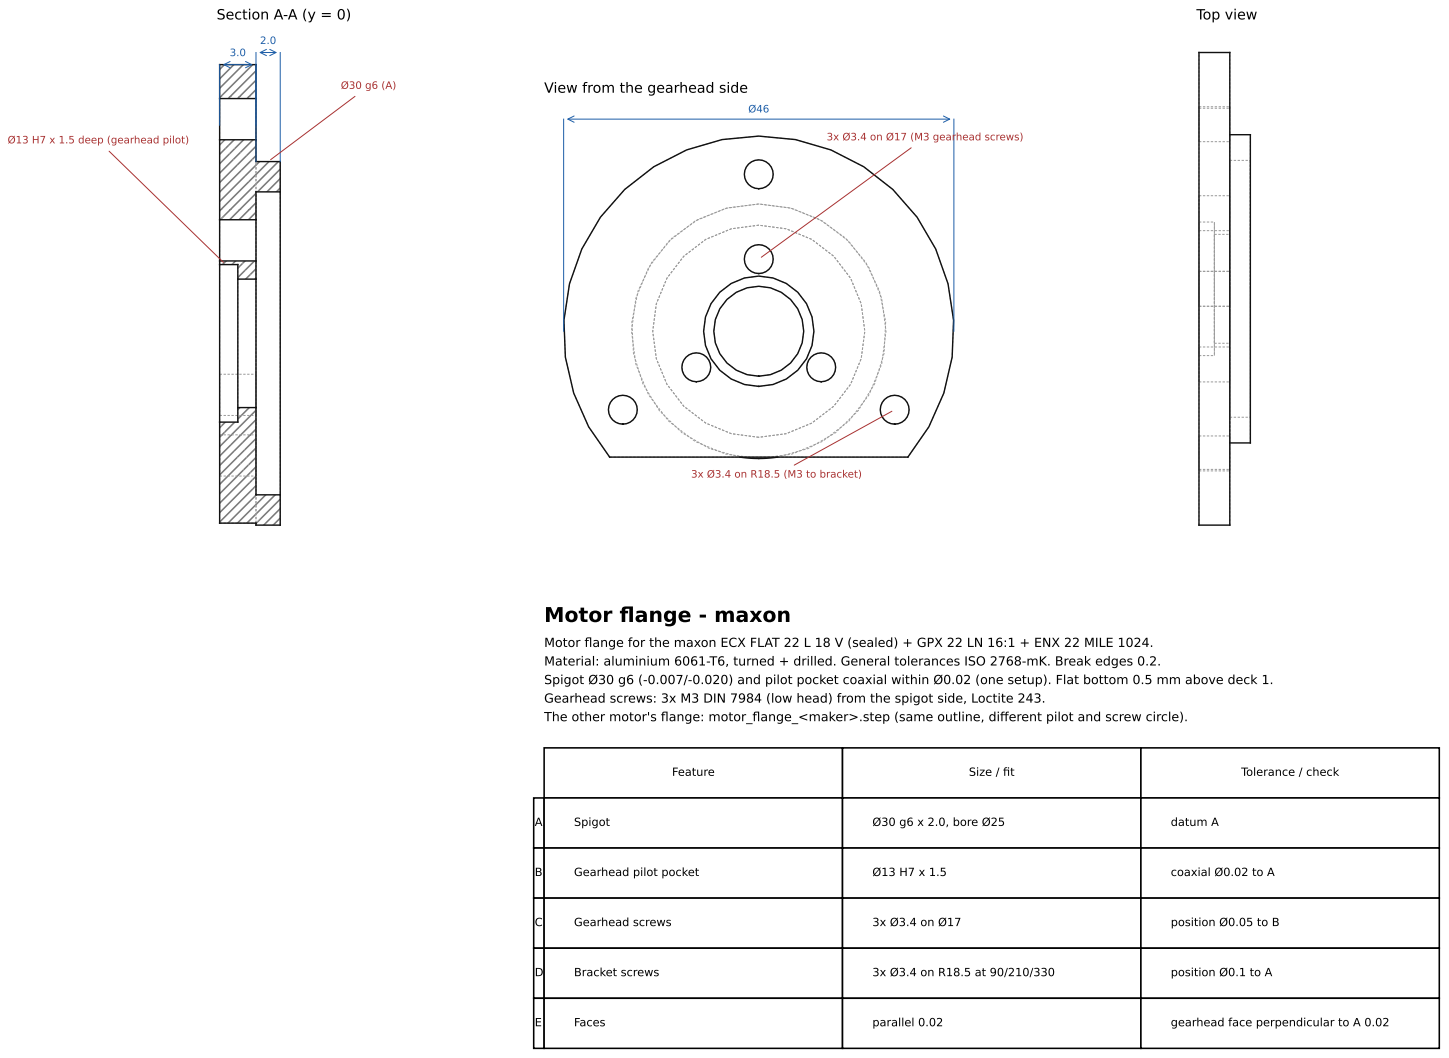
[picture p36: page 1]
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

View from the gearhead side

Ø13 H7 x 1.5 deep (gearhead pilot)

3x Ø3.4 on Ø17 (M3 gearhead screws)

3x Ø3.4 on R18.5 (M3 to bracket)

Motor flange - maxon

Motor flange for the maxon ECX FLAT 22 L 18 V (sealed) + GPX 22 LN 16:1 + ENX 22 MILE 1024.

Material: aluminium 6061-T6, turned + drilled. General tolerances ISO 2768-mK. Break edges 0.2.
Spigot Ø30 g6 (-0.007/-0.020) and pilot pocket coaxial within Ø0.02 (one setup). Flat bottom 0.5 mm above deck 1.
Gearhead screws: 3x M3 DIN 7984 (low head) from the spigot side, Loctite 243.
The other motor's flange: motor_flange_<maker>.step (same outline, different pilot and screw circle).

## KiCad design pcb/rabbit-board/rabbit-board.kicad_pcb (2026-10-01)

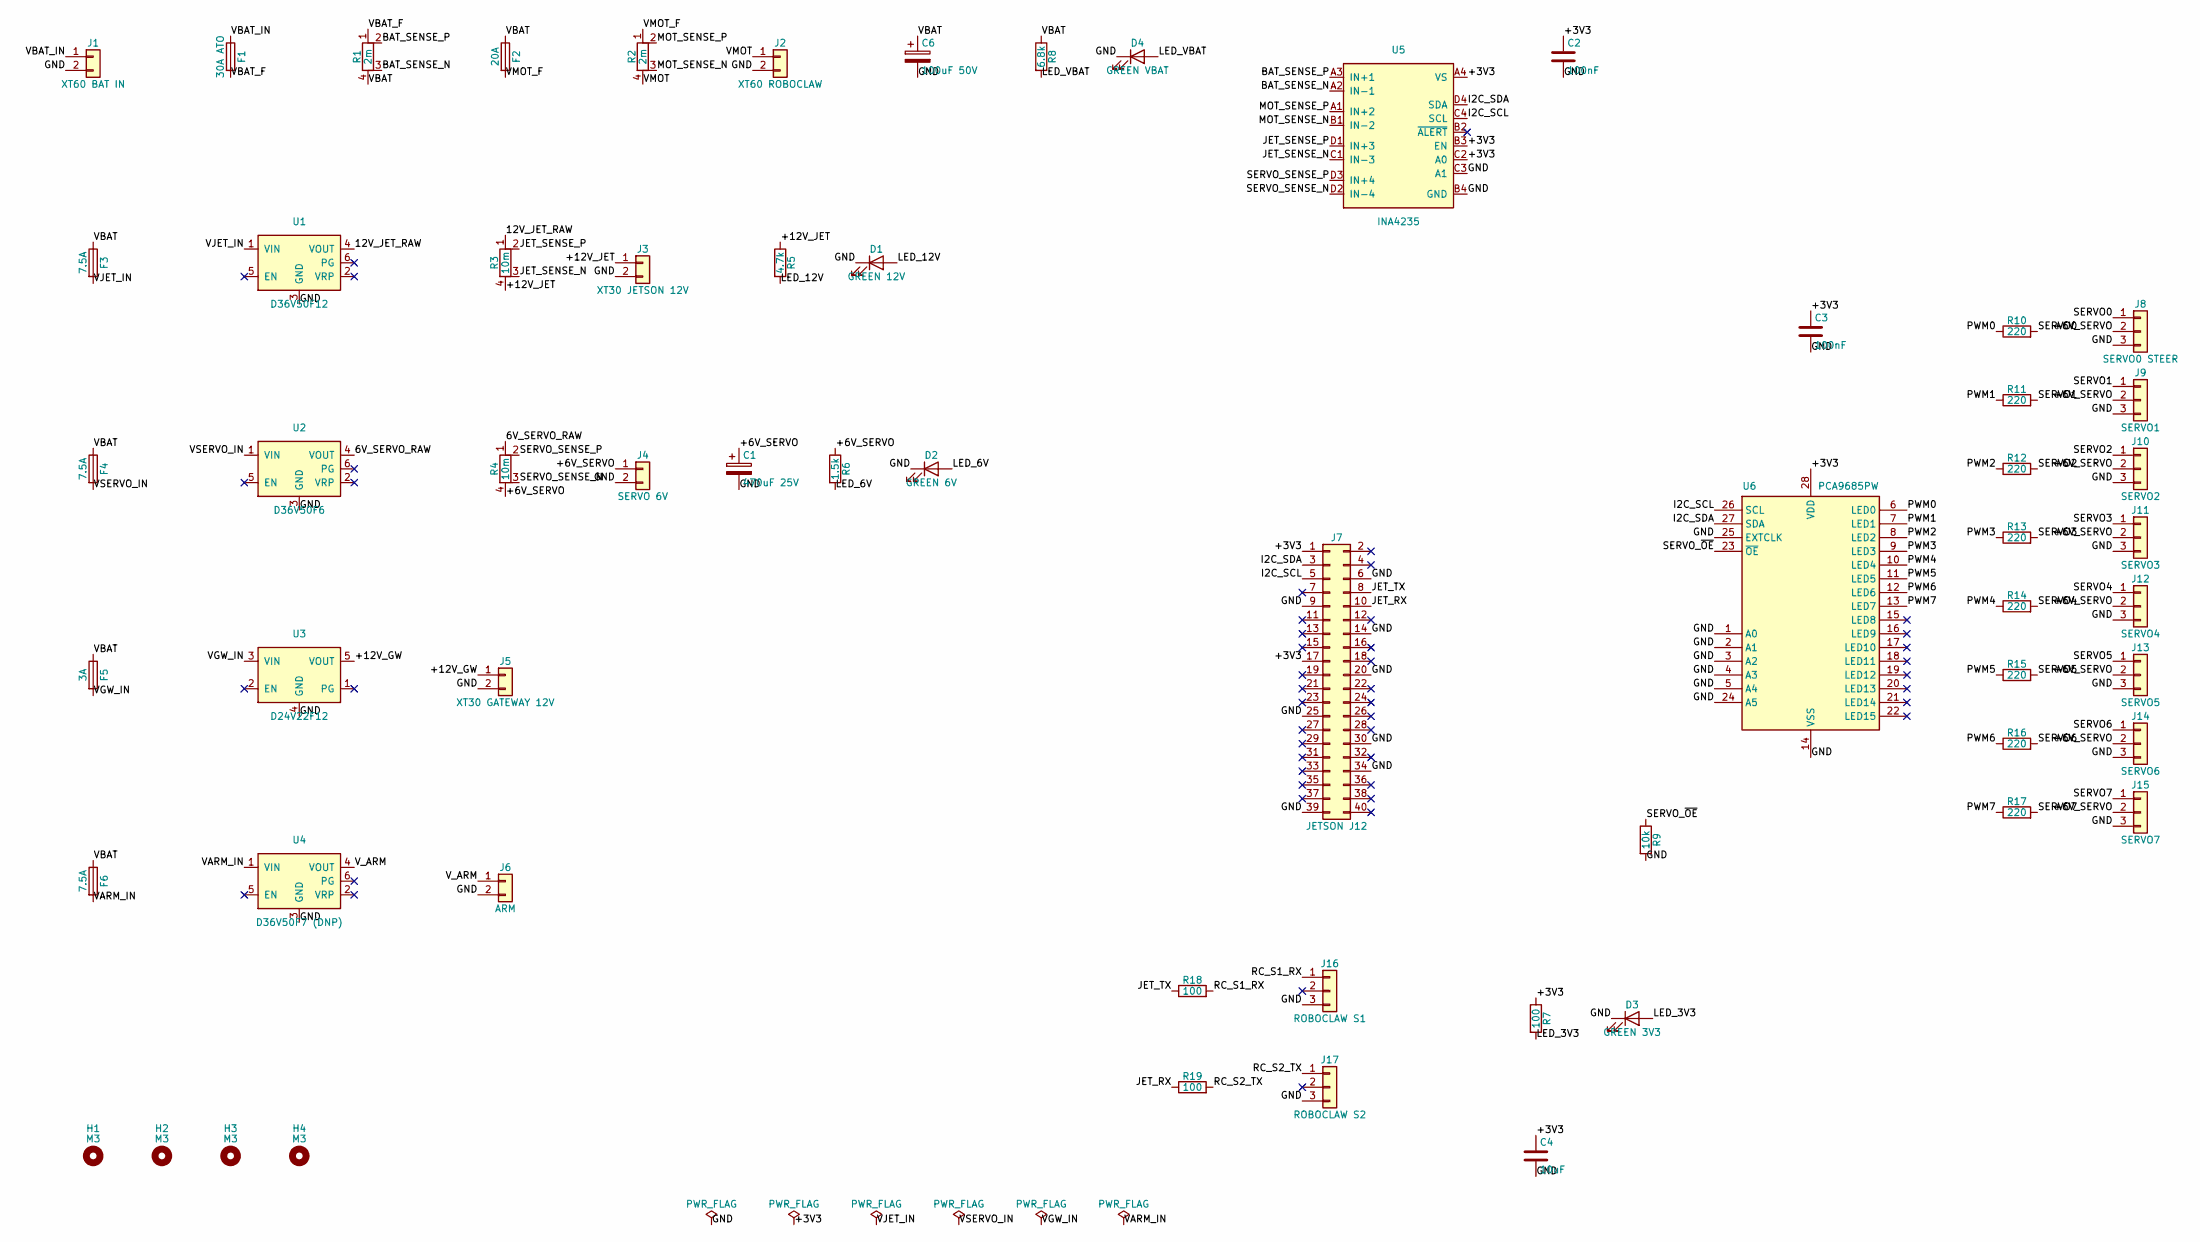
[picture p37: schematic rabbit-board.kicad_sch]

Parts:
C1: 470uF 25V; CP_Elec_8x10.5; LCSC C48935394
C2, C3: 100nF; C_0603_1608Metric; LCSC C14663
C4: 10uF; C_0805_2012Metric; LCSC C15850
C6: 100uF 50V; CP_Elec_6.3x7.7; LCSC C46550415
D1: GREEN 12V; LED_0805_2012Metric; LCSC C2297
D2: GREEN 6V; LED_0805_2012Metric; LCSC C2297
D3: GREEN 3V3; LED_0805_2012Metric; LCSC C2297
D4: GREEN VBAT; LED_0805_2012Metric; LCSC C2297
F1: 30A ATO; FuseHolder_Blade_ATO_Littelfuse_FLR_178.6165
F2: 20A; Fuseholder_Blade_Mini_Keystone_3568
F3, F4, F6: 7.5A; Fuseholder_Blade_Mini_Keystone_3568
F5: 3A; Fuseholder_Blade_Mini_Keystone_3568
H1, H2, H3, H4: M3; MountingHole_3.2mm_M3
J1: XT60 BAT IN; AMASS_XT60PW-M_1x02_P7.20mm_Horizontal
J2: XT60 ROBOCLAW; AMASS_XT60PW-F_1x02_P7.20mm_Horizontal
J3: XT30 JETSON 12V; AMASS_XT30PW-F_1x02_P2.50mm_Horizontal
J4: SERVO 6V; TerminalBlock_Phoenix_MKDS-1,5-2-5.08_1x02_P5.08mm_Horizont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
J5: XT30 GATEWAY 12V; AMASS_XT30PW-F_1x02_P2.50mm_Horizontal
J6: ARM; TerminalBlock_Phoenix_MKDS-1,5-2-5.08_1x02_P5.08mm_Horizont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
J7: JETSON J12; IDC-Header_2x20_P2.54mm_Vertical
J8: SERVO0 STEER; PinHeader_1x03_P2.54mm_Vertical
J9: SERVO1; PinHeader_1x03_P2.54mm_Vertical
J10: SERVO2; PinHeader_1x03_P2.54mm_Vertical
J11: SERVO3; PinHeader_1x03_P2.54mm_Vertical
J12: SERVO4; PinHeader_1x03_P2.54mm_Vertical
J13: SERVO5; PinHeader_1x03_P2.54mm_Vertical
J14: SERVO6; PinHeader_1x03_P2.54mm_Vertical
J15: SERVO7; PinHeader_1x03_P2.54mm_Vertical
J16: ROBOCLAW S1; PinHeader_1x03_P2.54mm_Vertical
J17: ROBOCLAW S2; PinHeader_1x03_P2.54mm_Vertical
R1, R2: 2m; R_Shunt_Vishay_WSK2512_6332Metric_T1.19mm; LCSC C3997408
R3, R4: 10m; R_Shunt_Vishay_WSK2512_6332Metric_T1.19mm; LCSC C3985410
R5: 4.7k; R_0603_1608Metric; LCSC C23162
R6: 1.5k; R_0603_1608Metric; LCSC C22843
R7, R18, R19: 100; R_0603_1608Metric; LCSC C22775
R8: 6.8k; R_0603_1608Metric; LCSC C23212
R9: 10k; R_0603_1608Metric; LCSC C25804
R10, R11, R12, R13, R14, R15, R16, R17: 220; R_0603_1608Metric; LCSC C22962
U1: D36V50F12; Pololu_D36V50Fx
U2: D36V50F6; Pololu_D36V50Fx
U3: D24V22F12; Pololu_D24V22Fx
U4: D36V50F7 (DNP); Pololu_D36V50Fx
U5: INA4235; TI_DSBGA-16_YBJ_1.5x1.5mm_P0.4mm; LCSC C33440856
U6: PCA9685PW; TSSOP-28_4.4x9.7mm_P0.65mm; LCSC C2678753

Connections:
/6V_SERVO_RAW: R4.1, U2.4 (VOUT)
/12V_JET_RAW: R3.1, U1.4 (VOUT)
/+3V3: C2.1, C3.1, C4.1, J7.1, J7.17, R7.1, U5.A4 (VS), U5.B3 (EN), U5.C2 (A0), U6.28 (VDD)
/+6V_SERVO: C1.1, J4.1, J8.2, J9.2, J10.2, J11.2, J12.2, J13.2, J14.2, J15.2, R4.4, R6.1
/+12V_GW: J5.1, U3.5 (VOUT)
/+12V_JET: J3.1, R3.4, R5.1
/BAT_SENSE_N: R1.3, U5.A2 (IN-1)
/BAT_SENSE_P: R1.2, U5.A3 (IN+1)
/GND: C1.2, C2.2, C3.2, C4.2, C6.2, D1.1 (K), D2.1 (K), D3.1 (K), D4.1 (K), J1.2, J2.2, J3.2, J4.2, J5.2, J6.2, J7.6, J7.9, J7.14, J7.20, J7.25, J7.30, J7.34, J7.39, J8.3, J9.3, J10.3, J11.3, J12.3, J13.3, J14.3, J15.3, J16.3, J17.3, R9.2, U1.3 (GND), U2.3 (GND), U3.4 (GND), U4.3 (GND), U5.B4 (GND), U5.C3 (A1), U6.1 (A0), U6.2 (A1), U6.3 (A2), U6.4 (A3), U6.5 (A4), U6.14 (VSS), U6.24 (A5), U6.25 (EXTCLK)
/I2C_SCL: J7.5, U5.C4 (SCL), U6.26 (SCL)
/I2C_SDA: J7.3, U5.D4 (SDA), U6.27 (SDA)
/JET_RX: J7.10, R19.1
/JET_SENSE_N: R3.3, U5.C1 (IN-3)
/JET_SENSE_P: R3.2, U5.D1 (IN+3)
/JET_TX: J7.8, R18.1
/LED_3V3: D3.2 (A), R7.2
/LED_6V: D2.2 (A), R6.2
/LED_12V: D1.2 (A), R5.2
/LED_VBAT: D4.2 (A), R8.2
/MOT_SENSE_N: R2.3, U5.B1 (IN-2)
/MOT_SENSE_P: R2.2, U5.A1 (IN+2)
/PWM0: R10.1, U6.6 (LED0)
/PWM1: R11.1, U6.7 (LED1)
/PWM2: R12.1, U6.8 (LED2)
/PWM3: R13.1, U6.9 (LED3)
/PWM4: R14.1, U6.10 (LED4)
/PWM5: R15.1, U6.11 (LED5)
/PWM6: R16.1, U6.12 (LED6)
/PWM7: R17.1, U6.13 (LED7)
/RC_S1_RX: J16.1, R18.2
/RC_S2_TX: J17.1, R19.2
/SERVO0: J8.1, R10.2
/SERVO1: J9.1, R11.2
/SERVO2: J10.1, R12.2
/SERVO3: J11.1, R13.2
/SERVO4: J12.1, R14.2
/SERVO5: J13.1, R15.2
/SERVO6: J14.1, R16.2
/SERVO7: J15.1, R17.2
/SERVO_SENSE_N: R4.3, U5.D2 (IN-4)
/SERVO_SENSE_P: R4.2, U5.D3 (IN+4)
/SERVO_~OE: R9.1, U6.23 (~OE)
/VARM_IN: F6.2, U4.1 (VIN)
/VBAT: C6.1, F2.1, F3.1, F4.1, F5.1, F6.1, R1.4, R8.1
/VBAT_F: F1.2, R1.1
/VBAT_IN: F1.1, J1.1
/VGW_IN: F5.2, U3.3 (VIN)
/VJET_IN: F3.2, U1.1 (VIN)
/VMOT: J2.1, R2.4
/VMOT_F: F2.2, R2.1
/VSERVO_IN: F4.2, U2.1 (VIN)
/V_ARM: J6.1, U4.4 (VOUT)

Board: 4 copper layers, 61 parts (0 on the bottom side), 52 nets, no tracks yet.

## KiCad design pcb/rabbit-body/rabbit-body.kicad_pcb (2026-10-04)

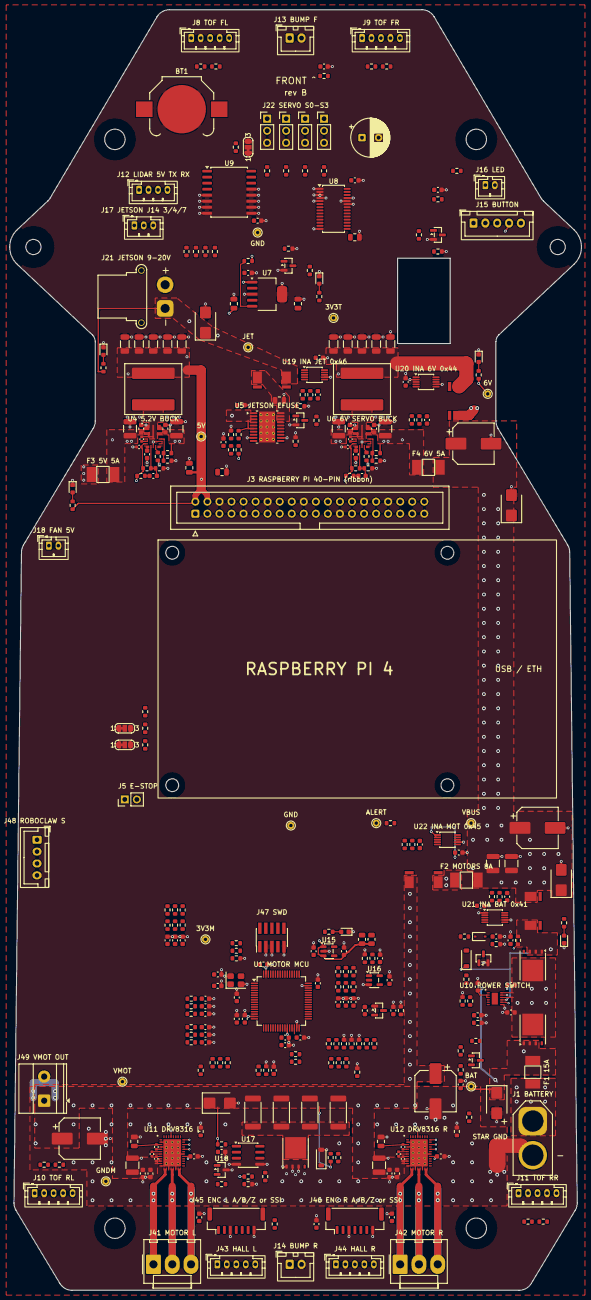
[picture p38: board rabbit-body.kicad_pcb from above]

Board: 4 copper layers, 120.5 x 269.9 mm, 346 parts (0 on the bottom side), 226 nets.

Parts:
BT1: CR1220; BatteryHolder_Keystone_3000_1x12mm
C3, C5, C10, C11, C12, C14A, C14B, C19, C20, C21, C22, C26, C27, C28, C29, C63, C70, C71, C72, C73, C81, C83, C87, C120, C121, C122, C123, C1101, C1102, C1201, C1202: 100nF; C_0603_1608Metric
C4, C6, C7, C9, C13, C1106, C1206: 10uF; C_0805_2012Metric
C8, C24, C86: 10nF; C_0603_1608Metric
C14: 470uF 16V; CP_Radial_D8.0mm_P3.50mm
C18: 2.2uF; C_0603_1608Metric
C23, C80: 47nF; C_0603_1608Metric
C25, C55, C85, C90, C406, C451, C461, C606, C1107, C1207: 1uF; C_0603_1608Metric
C30, C33, C1109, C1209: 220uF 35V; CP_Elec_8x10.5
C31, C32, C401, C402, C601, C602, C1103, C1203: 10uF 50V; C_1210_3225Metric
C82: 1uF; C_0805_2012Metric
C84, C91: 4.7uF; C_0603_1608Metric
C88, C89: 18pF; C_0603_1608Metric
C100, C101, C102, C103, C104, C105, C1110, C1111, C1112, C1210, C1211, C1212: 1nF; C_0603_1608Metric
C403, C404, C603, C604: 470nF; C_0603_1608Metric
C405, C407, C605, C607: 100nF; C_0402_1005Metric
C408, C608: 10pF; C_0603_1608Metric
C410, C411, C412, C413, C414, C610, C611, C612, C613, C614: 22uF; C_1206_3216Metric
C1104, C1204: 1uF; C_0402_1005Metric
C1105, C1205: 47nF; C_0402_1005Metric
D1, D10, D13, D14: SMBJ20A; D_SMB
D2, D3, D4, D5, D6, D93: LED red; LED_0603_1608Metric
D7: SMBJ20CA; D_SMB
D8: BZT52C8V2; D_SOD-123
D9: 1N4148WS; D_SOD-323
D11: BZT52C12; D_SOD-123
D12: BAT54S; SOT-23
F1: 15A; Fuse_Littelfuse_NANO2_451_2410
F2: 8A; Fuse_Littelfuse_NANO2_451_2410
F3, F4: 5A; Fuse_Littelfuse_NANO2_451_2410
H1, H2, H3, H4: deck standoff M4; MountingHole_4.3mm_M4
H5, H6: deck standoff M3; MountingHole_3.2mm_M3
J1: XT60 BAT; AMASS_XT60-M_1x02_P7.20mm_Vertical
J3: Pi 40-pin; IDC-Header_2x20_P2.54mm_Vertical
J5: E-stop loop; PinHeader_1x02_P2.54mm_Vertical
J8, J9, J10, J11: ToF; JST_PH_B5B-PH-K_1x05_P2.00mm_Vertical
J12: lidar C1; JST_PH_B4B-PH-K_1x04_P2.00mm_Vertical
J13: bumpers front; JST_XH_B2B-XH-A_1x02_P2.50mm_Vertical
J14: bumpers rear; JST_XH_B2B-XH-A_1x02_P2.50mm_Vertical
J15: button; JST_XH_B5B-XH-A_1x05_P2.50mm_Vertical
J16: status LED; JST_PH_B2B-PH-K_1x02_P2.00mm_Vertical
J17: Jetson UART; JST_PH_B3B-PH-K_1x03_P2.00mm_Vertical
J18: Pi fan 5V; JST_PH_B2B-PH-K_1x02_P2.00mm_Vertical
J21: XT30 JETSON; AMASS_XT30PW-F_1x02_P2.50mm_Horizontal
J22: servo 0; PinHeader_1x03_P2.54mm_Vertical
J23: servo 1; PinHeader_1x03_P2.54mm_Vertical
J24: servo 2; PinHeader_1x03_P2.54mm_Vertical
J25: servo 3; PinHeader_1x03_P2.54mm_Vertical
J41, J42: motor phases; Molex_KK-396_A-41791-0003_1x03_P3.96mm_Vertical
J43, J44: Halls; JST_PH_B5B-PH-K_1x05_P2.00mm_Vertical
J45, J46: encoder; JST_GH_BM07B-GHS-TBT_1x07-1MP_P1.25mm_Vertical
J47: SWD; PinHeader_2x05_P1.27mm_Vertical_SMD
J48: RoboClaw S; JST_XH_B4B-XH-A_1x04_P2.50mm_Vertical
J49: MOT_BUS out; TerminalBlock_Phoenix_MKDS-1,5-2-5.08_1x02_P5.08mm_Horizont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
JP1: UART0 TX; SolderJumper-3_P1.3mm_Bridged12_RoundedPad1.0x1.5mm_NumberL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
JP2: UART0 RX; SolderJumper-3_P1.3mm_Bridged12_RoundedPad1.0x1.5mm_NumberL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
JP3: S0 source; SolderJumper-3_P1.3mm_Bridged12_RoundedPad1.0x1.5mm_NumberL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
L4, L6: 3.3uH; L_Coilcraft_XAL1010-XXX
MOD1: Raspberry Pi 4; RaspberryPi4_Standoffs
NT1: star GND; NetTie_3.5mm
Q1, Q2: BSC010N04LS; TDSON-8-1
Q3, Q5, Q7, Q8: AO3400A; SOT-23
Q4: MMBT3906; SOT-23
Q6: BSC026N04LS; TDSON-8-1
R1: 2mR 3W; R_Shunt_2512_Kelvin
R2, R4: 10mR 1W; R_Shunt_2512_Kelvin
R3: 5mR 3W; R_Shunt_2512_Kelvin
R9A, R17, R28, R31, R39, R41, R58, R60, R64, R65, R66, R81, R83, R90, R95, R99: 10k; R_0603_1608Metric
R10, R11, R12, R13, R16, R42, R55, R1102, R1103, R1104, R1202, R1203, R1204: 100; R_0603_1608Metric
R14, R15, R22, R24, R32B, R33B, R36, R48, R86, R91, R92, R93, R100, R101, R102, R103, R104, R105: 1k; R_0603_1608Metric
R14B, R18, R23, R25, R26, R43, R61, R63, R87, R96, R97, R98, R401, R404, R601, R604: 100k; R_0603_1608Metric
R27, R40A: 330; R_0603_1608Metric
R29, R30, R38, R56, R110, R111, R112, R113, R114, R115, R120A, R120B, R121A, R121B, R122A, R122B, R123A, R123B: 4.7k; R_0603_1608Metric
R32, R33, R34, R35, R89: 220; R_0603_1608Metric
R37: 1.5k; R_0603_1608Metric
R40, R82: 150k; R_0603_1608Metric
R44, R405, R605: 22k; R_0603_1608Metric
R45, R47: 47k; R_0603_1608Metric
R46: 220k; R_0603_1608Metric
R49: 1M; R_0603_1608Metric
R50, R51, R52, R53: 39R 2W; R_2512_6332Metric
R57: 60.4k; R_0603_1608Metric
R59: 1.5M; R_0603_1608Metric
R62: 33k; R_0603_1608Metric
R80: 68k; R_0603_1608Metric
R84: 3.9k; R_0603_1608Metric
R94: 5.1k; R_0603_1608Metric
R130, R131, R132, R133, R134, R135: 22; R_0603_1608Metric
R402: 24k; R_0603_1608Metric
R403, R603: 4.99k; R_0603_1608Metric
R406, R606: 39k; R_0603_1608Metric
R451, R461: 10; R_0805_2012Metric
R602: 20k; R_0603_1608Metric
R701, R702, R711, R712, R721, R722, R731, R732: 10; R_0603_1608Metric
R1101, R1201: 22; R_0402_1005Metric
RT65, RT66: NTC 10k; R_0603_1608Metric
TP1: VBUS; TestPoint_THTPad_D1.5mm_Drill0.7mm
TP2: +5V; TestPoint_THTPad_D1.5mm_Drill0.7mm
TP3: SERVO_6V; TestPoint_THTPad_D1.5mm_Drill0.7mm
TP4: JET_PWR; TestPoint_THTPad_D1.5mm_Drill0.7mm
TP5: +3V3_TOF; TestPoint_THTPad_D1.5mm_Drill0.7mm
TP6, TP7: GND; TestPoint_THTPad_D1.5mm_Drill0.7mm
TP8: INA_ALERT; TestPoint_THTPad_D1.5mm_Drill0.7mm
TP9: MOT_BUS; TestPoint_THTPad_D1.5mm_Drill0.7mm
TP10: +3V3_MCU; TestPoint_THTPad_D1.5mm_Drill0.7mm
TP11: GND_MOT; TestPoint_THTPad_D1.5mm_Drill0.7mm
TP12: BAT_F; TestPoint_THTPad_D1.5mm_Drill0.7mm
U1: STM32G474RET6; LQFP-64_10x10mm_P0.5mm
U4, U6: LM61495; TI_RPH0016B_VQFN-HR-16_3.5x4.5mm
U5: TPS16630; HTSSOP-20-1EP_4.4x6.5mm_P0.65mm_EP3.4x6.5mm_Mask2.96x2.96mm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
U7: TPS73733; SOT-223-6
U8: PCA9685PW; TSSOP-28_4.4x9.7mm_P0.65mm
U9: DS3231SN; SOIC-16W_7.5x10.3mm_P1.27mm
U10: LM74800; TI_DRR0012E_WSON-12_3x3mm_P0.5mm_EP1.3x2.5mm
U11, U12: DRV8316CR; TI_RGF0040E_VQFN-40_5x7mm_P0.5mm_EP3.7x5.7mm
U15: TLV75533; SOT-23-5
U16: SN74LVC1G132; SOT-23-5
U17: LM393; SOIC-8_3.9x4.9mm_P1.27mm
U18: TL431; SOT-23
U19, U20, U21, U22: INA226; MSOP-10_3x3mm_P0.5mm
Y1: 8MHz; Crystal_SMD_3225-4Pin_3.2x2.5mm

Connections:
5V_HALL_L: C451.1, J43.1, J45.1, R451.2
5V_HALL_R: C461.1, J44.1, J46.1, R461.2
6V_RAW: C607.2, C610.1, C611.1, C612.1, C613.1, C614.1, L6.2, R2.1, R601.1, R603.1, U6.5
+3V3_MCU: C19.1, C84.1, C85.1, C86.1, C91.1, C120.1, C121.1, C122.1, C123.1, J45.2, J46.2, J47.1, R9A.2, R65.1, R66.1, R94.2, R95.2, R99.2, R110.2, R111.2, R112.2, R113.2, R114.2, R115.2, TP10.1, U1.1, U1.16, U1.28, U1.29, U1.32, U1.48, U1.64, U15.5, U16.5
+3V3_PI: C3.1, C4.1, C5.1, C13.1, C27.1, C28.1, C29.1, C83.1, J3.1, J3.17, R28.2, R29.2, R30.2, R31.2, U8.28, U9.2, U19.1, U19.6, U20.1, U20.6, U21.2, U21.6, U22.1, U22.2, U22.6
+3V3_TOF: C7.1, J8.1, J9.1, J10.1, J11.1, R40A.1, R120A.2, R120B.2, R121A.2, R121B.2, R122A.2, R122B.2, R123A.2, R123B.2, TP5.1, U7.2
+5V: C6.1, C9.1, C90.1, C407.2, C410.1, C411.1, C412.1, C413.1, C414.1, J3.2, J3.4, J12.1, J15.4, J18.1, L4.2, R26.2, R36.1, R401.1, R403.1, R451.1, R461.1, TP2.1, U4.5, U7.1, U15.1, U15.3
ADC_AL: C1110.1, R1102.2, U1.12
ADC_AR: C1210.1, R1202.2, U1.9
ADC_BL: C1111.1, R1103.2, U1.13
ADC_BR: C1211.1, R1203.2, U1.10
ADC_CL: C1112.1, R1104.2, U1.8
ADC_CR: C1212.1, R1204.2, U1.11
ALIVE_AC: C14A.2, D12.3
ALIVE_DET: C14B.1, D12.2, R14B.1, U16.2
AVDD_L: C1107.1, U11.25, U11.37
AVDD_R: C1207.1, U12.25, U12.37
BAT_F: C22.1, D7.1, F1.2, Q1.1, Q1.2, Q1.3, Q4.2, R43.1, TP12.1, U10.2, U10.3
BAT_IN: F1.1, J1.1
BK_L: C1106.1, R1101.2, U11.3
BK_R: C1206.1, R1201.2, U12.3
BODY_IN: C401.1, C402.1, C403.1, C404.1, F3.2, R404.2, U4.2, U4.14
BOOT4: C405.1, U4.3, U4.4
BOOT6: C605.1, U6.3, U6.4
BRK_D: Q6.5, R50.1, R51.1, R52.1, R53.1
BRK_G: D11.1, Q6.4, R59.1, R60.2, R61.1, U17.1
BRK_REF: R56.2, U17.2, U17.6, U18.1, U18.2
BRK_SENSE: R61.2, R62.1, U1.23
BRK_SNS: R57.2, R58.1, R59.2, U17.3
BRK_VCC: C55.1, R55.2, U17.8
BTN_LED_K: J15.5, Q3.3
BTN_ON: C26.1, J15.1, R44.2
BUMPER_FRONT: C11.1, J3.38, J13.1, R29.1, R32B.1
BUMPER_REAR: C12.1, J3.40, J14.1, R30.1, R33B.1
BUMP_F_M: R32B.2, U1.25
BUMP_R_M: R33B.2, U1.26
CPH_L: C1105.1, U11.7
CPH_R: C1205.1, U12.7
CPL_L: C1105.2, U11.6
CPL_R: C1205.2, U12.6
CP_L: C1104.2, U11.8
CP_R: C1204.2, U12.8
DG: Q1.4, U10.1
DRVOFF: U11.21, U12.21, U16.4
DRV_NFAULT: R94.1, U1.20, U11.22, U12.22
DRV_NSLEEP: R96.1, U1.24, U11.23, U12.23
EN4: R404.1, R405.1, U4.13
EN6: R604.1, R605.1, U6.13
ENC_L_A: J45.4, R131.2
ENC_L_A_M: R131.1, U1.59
ENC_L_B: J45.5, R132.1
ENC_L_B_M: R132.2, U1.60
ENC_L_Z: J45.6, R130.2
ENC_L_Z_M: R130.1, U1.56
ENC_R_A: J46.4, R134.2
ENC_R_A_M: R134.1, U1.57
ENC_R_B: J46.5, R135.1
ENC_R_B_M: R135.2, U1.58
ENC_R_Z: J46.6, R133.2
ENC_R_Z_M: R133.1, U1.41
ESTOP: J5.2, J48.3, R17.1, R18.1, U1.34, U1.55
ESTOP_A: J5.1, R16.2
ESTOP_DLY: C18.1, R18.2, U16.1
FB4: C408.2, R401.2, R402.1, U4.7
FB6: C608.2, R601.2, R602.1, U6.7
FF4: C408.1, R403.2
FF6: C608.1, R603.2
GND: BT1.2, C3.2, C4.2, C5.2, C6.2, C7.2, C8.2, C9.2, C10.2, C11.2, C12.2, C13.2, C14.2, C14B.2, C18.2, C19.2, C21.2, C22.2, C23.2, C24.2, C25.2, C26.2, C27.2, C28.2, C29.2, C30.2, C31.2, C32.2, C33.2, C63.2, C80.2, C81.2, C82.2, C83.2, C84.2, C85.2, C86.2, C87.2, C88.2, C89.2, C90.2, C91.2, C100.2, C101.2, C102.2, C103.2, C104.2, C105.2, C120.2, C121.2, C122.2, C123.2, C401.2, C402.2, C403.2, C404.2, C406.1, C407.1, C410.2, C411.2, C412.2, C413.2, C414.2, C451.2, C461.2, C601.2, C602.2, C603.2, C604.2, C606.1, C607.1, C610.2, C611.2, C612.2, C613.2, C614.2, C1110.2, C1111.2, C1112.2, C1210.2, C1211.2, C1212.2, D1.2, D2.1, D3.1, D4.1, D5.1, D6.1, D7.2, D12.1, D13.2, D14.2, D93.1, J1.2, J3.6, J3.9, J3.14, J3.20, J3.25, J3.30, J3.34, J3.39, J8.2, J8.4, J9.2, J9.4, J10.2, J10.4, J11.2, J11.4, J12.2, J13.2, J14.2, J15.2, J16.2, J17.3, J18.2, J21.2, J22.3, J23.3, J24.3, J25.3, J43.2, J44.2, J45.3, J45.7, J46.3, J46.7, J47.3, J47.5, J47.9, J48.4, NT1.2, Q3.2, Q5.2, Q7.2, Q8.2, R14B.2, R17.2, R23.2, R25.2, R41.2, R46.2, R49.2, R62.2, R64.2, R81.2, R83.2, R84.2, R87.2, R90.2, R96.2, R97.2, R98.2, R402.2, R405.2, R406.1, R602.2, R605.2, R606.1, TP6.1, TP7.1, U1.15, U1.27, U1.31, U1.47, U1.63, U4.1, U4.8, U4.11, U4.12, U4.15, U5.9, U5.12, U5.21, U6.1, U6.8, U6.11, U6.12, U6.15, U7.3, U7.6, U8.1, U8.2, U8.3, U8.4, U8.5, U8.14, U8.23, U8.24, U8.25, U9.5, U9.6, U9.7, U9.8, U9.9, U9.10, U9.11, U9.12, U9.13, U10.7, U15.2, U16.3, U19.7, U20.2, U20.7, U21.1, U21.7, U22.7, Y1.2, Y1.4
GND_MOT: C55.2, C1101.1, C1102.1, C1103.2, C1106.2, C1107.2, C1109.2, C1201.1, C1202.1, C1203.2, C1206.2, C1207.2, C1209.2, D10.2, D11.2, J49.2, NT1.1, Q6.1, Q6.2, Q6.3, R58.2, RT65.2, RT66.2, TP11.1, U11.2, U11.4, U11.12, U11.15, U11.18, U11.26, U11.41, U12.2, U12.4, U12.12, U12.15, U12.18, U12.26, U12.41, U17.4, U17.5, U18.3
GPIO0: J3.27, R91.1
GPIO1: J3.28, R92.1
GPIO8: J3.24, R12.1
GPIO9: J3.21, R13.2
GPIO12: J3.32, R14.1
GPIO13: J3.33, R15.2
GPIO14: J3.8, R10.1
GPIO15: J3.10, R11.2
GPIO16: J3.36, R16.1
GPIO17: J3.11, R48.1
GPIO18: J3.12, R22.1
GPIO19: J3.35, R27.1
GPIO25: J3.22, R86.1
GPIO27: J3.13, R24.1
HG: Q2.4, R42.1, U10.8
HG_DV: C23.1, R42.2
HLA: J43.3, R100.1, R110.1
HLA_M: C100.1, R100.2, U1.2
HLB: J43.4, R101.1, R111.1
HLB_M: C101.1, R101.2, U1.3
HLC: J43.5, R102.1, R112.1
HLC_M: C102.1, R102.2, U1.4
HOLD_Z: D8.2, R47.1
HRA: J44.3, R103.1, R113.1
HRA_M: C103.1, R103.2, U1.45
HRB: J44.4, R104.1, R114.1
HRB_M: C104.1, R104.2, U1.46
HRC: J44.5, R105.1, R115.1
HRC_M: C105.1, R105.2, U1.62
I2C1_SCL: J3.5, U8.26, U9.16, U19.5, U20.5, U21.5, U22.5
I2C1_SDA: J3.3, U8.27, U9.15, U19.2, U19.4, U20.4, U21.4, U22.4
INA1_N: C70.2, R702.2, U21.8, U21.9
INA1_P: C70.1, R701.2, U21.10
INA2_N: C73.2, R732.2, U20.8, U20.9
INA2_P: C73.1, R731.2, U20.10
INA3_N: C71.2, R712.2, U22.8, U22.9
INA3_P: C71.1, R711.2, U22.10
INA4_N: C72.2, R722.2, U19.8, U19.9
INA4_P: C72.1, R721.2, U19.10
INA_ALERT: J3.18, R31.1, TP8.1, U19.3, U20.3, U21.3, U22.3
INHA_L: U1.42, U11.27
INHA_R: U1.38, U12.27
INHB_L: U1.43, U11.29
INHB_R: U1.39, U12.29
INHC_L: U1.44, U11.31
INHC_R: U1.40, U12.31
INL_L: R97.1, U1.30, U11.28, U11.30, U11.32
INL_R: R98.1, U1.19, U12.28, U12.30, U12.32
JET_DVDT: C80.1, U5.10
JET_ILIM: R84.1, U5.11
JET_OUT: C82.1, R4.1, U5.18, U5.19, U5.20
JET_OVP: R82.2, R83.1, U5.8
JET_PWR: D14.1, J21.1, R4.2, R38.1, TP4.1
JET_SHDN: Q7.3, U5.13
JET_UART_RX: J17.1, R14.2
JET_UART_TX: J17.2, R15.1
JET_UVLO: R80.1, R81.1, U5.7
LATCH_B: Q4.1, R43.2, R44.1
LATCH_C: Q4.3, R45.1
LED5_A: D2.2, R36.2
LED6_A: D3.2, R37.2
LED12_A: D4.2, R38.2
LED33_A: D6.2, R40A.2
LEDB_A: D5.2, R39.1
LIDAR_RX: J12.4, R12.2
LIDAR_TX: J12.3, R13.1
LM_CAP: C20.1, U10.11
LM_EN: C24.1, Q5.3, R45.2, R46.1, R47.2, U10.6
LM_OV: R40.2, R41.1, U10.5
LM_SW: R40.1, U10.4
MCU_ALIVE: C14A.1, U1.35
MCU_BOOT0: R90.1, R91.2, U1.61
MCU_LED: R93.1, U1.36
MCU_LED_A: D93.2, R93.2
MCU_NRST: C87.1, J47.10, R92.2, U1.7
MCU_RX: JP1.1, U1.17
MCU_TX: JP2.1, U1.14
MLA: J41.1, U11.13, U11.14
MLB: J41.2, U11.16, U11.17
MLC: J41.3, U11.19, U11.20
MOT_BUS: C1101.2, C1102.2, C1103.1, C1104.1, C1109.1, C1201.2, C1202.2, C1203.1, C1204.1, C1209.1, D10.1, J49.1, R3.2, R50.2, R51.2, R52.2, R53.2, R55.1, R56.1, R57.1, R60.1, R63.1, TP9.1, U11.9, U11.10, U11.11, U12.9, U12.10, U12.11
MOT_F: F2.2, R3.1
MRA: J42.1, U12.13, U12.14
MRB: J42.2, U12.16, U12.17
MRC: J42.3, U12.19, U12.20
NSCS_L: R99.1, U1.51, U11.36
NSCS_R: R9A.1, U1.37, U12.36
NTC_L: R65.2, RT65.1, U1.22
NTC_R: R66.2, RT66.1, U1.33
OFF_A: D9.2, R48.2
OFF_G: C25.1, D9.1, Q5.1, R49.1
OSC_IN: C88.1, U1.5, Y1.1
OSC_OUT: C89.1, U1.6, Y1.3
PCA_LED0: R32.1, U8.6
PCA_LED1: R33.1, U8.7
PCA_LED2: R34.1, U8.8
PCA_LED3: R35.1, U8.9
POWER_BTN: C10.1, J3.37, J15.3, R28.1
PWM0: J22.1, JP3.2
PWM0_MCU: JP3.3, R89.2
PWM0_PCA: JP3.1, R32.2
PWM1: J23.1, R33.2
PWM2: J24.1, R34.2
PWM3: J25.1, R35.2
Q3_G: Q3.1, R24.2, R25.1
Q7_G: Q7.1, R86.2, R87.1
Q8_G: Q8.1, R22.2, R23.1
RC_S1: J48.1, JP1.3
RC_S2: J48.2, JP2.3
RT4: R406.2, U4.9
RT6: R606.2, U6.9
RTC_VBAT: BT1.1, U9.14
SERVO_6V: C14.1, J22.2, J23.2, J24.2, J25.2, R2.2, R37.1, TP3.1
SERVO_MCU: R89.1, U1.21
SH1_N: R1.4, R702.1
SH1_P: R1.3, R701.1
SH2_N: R2.4, R732.1
SH2_P: R2.3, R731.1
SH3_N: R3.4, R712.1
SH3_P: R3.3, R711.1
SH4_N: R4.4, R722.1
SH4_P: R4.3, R721.1
SOA_L: R1102.1, U11.40
SOA_R: R1202.1, U12.40
SOB_L: R1103.1, U11.39
SOB_R: R1203.1, U12.39
SOC_L: R1104.1, U11.38
SOC_R: R1204.1, U12.38
SPI_MISO: R95.1, U1.53, U11.33, U12.33
SPI_MOSI: U1.54, U11.34, U12.34
SPI_SCK: U1.52, U11.35, U12.35
STATUS_LED_A: J16.1, R27.2
STEER_IN: C601.1, C602.1, C603.1, C604.1, F4.2, R604.2, U6.2, U6.14
SW4: C405.2, L4.1, U4.16
SW6: C605.2, L6.1, U6.16
SWBK_L: R1101.1, U11.5
SWBK_R: R1201.1, U12.5
SWCLK: J47.4, U1.50
SWDIO: J47.2, U1.49
SW_MID: C20.2, C21.1, Q1.5, Q2.5, U10.10, U10.12
TOF_EN: Q8.3, R26.1, U7.5
TOF_FL_SCL: J3.29, J8.3, R120A.1
TOF_FL_SDA: J3.7, J8.5, R120B.1
TOF_FR_SCL: J3.26, J9.3, R121A.1
TOF_FR_SDA: J3.31, J9.5, R121B.1
TOF_RL_SCL: J3.23, J10.3, R122A.1
TOF_RL_SDA: J3.19, J10.5, R122B.1
TOF_RR_SCL: J3.16, J11.3, R123A.1
TOF_RR_SDA: J3.15, J11.5, R123B.1
TPS_NR: C8.1, U7.4
UART0_RX: JP2.2, R11.1
UART0_TX: JP1.2, R10.2
VBUS: C30.1, C31.1, C32.1, C33.1, C81.1, D1.1, D13.1, F2.1, F3.1, F4.1, R1.2, R39.2, R80.2, R82.1, TP1.1, U5.1, U5.2, U5.3, U5.6
VBUS_RAW: D8.1, Q2.1, Q2.2, Q2.3, R1.1, U10.9
VCC4: C406.2, U4.6
VCC6: C606.2, U6.6
VMOT_SENSE: C63.1, R63.2, R64.1, U1.18

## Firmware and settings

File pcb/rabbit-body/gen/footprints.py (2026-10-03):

"""Custom footprints of the body board (rev B), written to lib/rabbit_body.pretty (the directory is rebuilt).

Pad positions come from the vendor land patterns (top view, KiCad frame: x right, y down):
- DRV8316 RGF0040E VQFN-40 5 x 7: SLVSF16B p.93;
- LM61495 RPH0016B VQFN-HR-16 4.5 x 3.5 (notched corner pads): SNVSBZ4A p.59, measured off the vector drawing;
- LM74800 DRR0012E WSON-12 3 x 3: SNOSDD8 p.41 (exposed pad left floating, p.3);
- Littelfuse NANO2 451 2410 fuse: 451/453 datasheet, "Recommended pad layout" (pads 1.96 x 3.15, gap 2.95);
- Raspberry Pi 4: mechanical drawing, holes 58 x 49, 3.5 from the edges.
"""
import shutil
from pathlib import Path

LIB = Path(__file__).resolve().parents[1] / "lib" / "rabbit_body.pretty"
M3D = "${KIPRJMOD}/3d/"


def _f(v):
    return f"{v:.4f}".rstrip("0").rstrip(".")


class FP:
    def __init__(self, name, descr, attr="smd"):
        self.name, self.descr, self.attr = name, descr, attr
        self.items = []
        self.model = None

    def tht(self, num, x, y, size, drill, shape="circle", layers='"*.Cu" "*.Mask"'):
        sx, sy = (size, size) if not isinstance(size, tuple) else size
        self.items.append(f'  (pad "{num}" thru_hole {shape} (at {_f(x)} {_f(y)}) (size {_f(sx)} {_f(sy)}) '
                          f'(drill {_f(drill)}) (layers {layers}) (remove_unused_layers no))')

    def npth(self, x, y, d):
        self.items.append(f'  (pad "" np_thru_hole circle (at {_f(x)} {_f(y)}) (size {_f(d)} {_f(d)}) '
                          f'(drill {_f(d)}) (layers "*.Cu" "*.Mask"))')

    def smd(self, num, x, y, sx, sy, shape="roundrect", paste=True, paste_margin=None, mask=True):
        layers = '"F.Cu"' + (' "F.Paste"' if paste else "") + (' "F.Mask"' if mask else "")
        extra = f' (solder_paste_margin {_f(paste_margin)})' if paste_margin is not None else ""
        rr = " (roundrect_rratio 0.2)" if shape == "roundrect" else ""
        self.items.append(f'  (pad "{num}" smd {shape} (at {_f(x)} {_f(y)}) (size {_f(sx)} {_f(sy)}) '
                          f'(layers {layers}){rr}{extra})')

    def paste(self, x, y, sx, sy):
        self.items.append(f'  (pad "" smd rect (at {_f(x)} {_f(y)}) (size {_f(sx)} {_f(sy)}) (layers "F.Paste"))')

    def poly_pad(self, num, rects):
        """Custom pad = union of rectangles (x0, y0, x1, y1), anchored at the first rectangle's centre."""
        x0, y0, x1, y1 = rects[0]
        ax, ay = (x0 + x1) / 2, (y0 + y1) / 2
        a = min(x1 - x0, y1 - y0) * 0.5
        prims = []
        for r0x, r0y, r1x, r1y in rects:
            pts = [(r0x, r0y), (r1x, r0y), (r1x, r1y), (r0x, r1y)]
            prims.append("(gr_poly (pts " + " ".join(f"(xy {_f(px - ax)} {_f(py - ay)})" for px, py in pts) +
                         ") (width 0) (fill yes))")
        self.items.append(f'  (pad "{num}" smd custom (at {_f(ax)} {_f(ay)}) (size {_f(a)} {_f(a)}) '
                          f'(layers "F.Cu" "F.Paste" "F.Mask") (options (clearance outline) (anchor rect)) '
                          f'(primitives {" ".join(prims)}))')

    def rect(self, layer, x0, y0, x1, y1, w=None):
        w = w or {"F.CrtYd": 0.05, "F.SilkS": 0.12, "F.Fab": 0.1}.get(layer, 0.1)
        self.items.append(f'  (fp_rect (start {_f(x0)} {_f(y0)}) (end {_f(x1)} {_f(y1)}) '
                          f'(stroke (width {w}) (type solid)) (fill no) (layer "{layer}"))')

    def circle(self, layer, x, y, r, w=0.12, fill=False):
        self.items.append(f'  (fp_circle (center {_f(x)} {_f(y)}) (end {_f(x + r)} {_f(y)}) '
                          f'(stroke (width {w}) (type solid)) (fill {"yes" if fill else "no"}) (layer "{layer}"))')

    def text(self, layer, s, x, y, size=1.0):
        self.items.append(f'  (fp_text user "{s}" (at {_f(x)} {_f(y)}) (layer "{layer}") '
                          f'(effects (font (size {size} {size}) (thickness {max(0.15, size * 0.15):.3f}))))')

    def box(self, x0, y0, x1, y1, crt=0.25, silk=True):
        self.rect("F.Fab", x0, y0, x1, y1)
        if silk:
            self.rect("F.SilkS", x0 - 0.1, y0 - 0.1, x1 + 0.1, y1 + 0.1)
        self.rect("F.CrtYd", x0 - crt, y0 - crt, x1 + crt, y1 + crt)

    def pin1(self, x, y):
        self.circle("F.SilkS", x, y, 0.15, 0.1, True)

    def set_model(self, path, z=0.0, rot=0.0):
        self.model = (path, z, rot)

    def write(self, ref_y=None, val_y=None):
        ref_y = ref_y if ref_y is not None else 0
        out = [f'(footprint "{self.name}"', '  (version 20241229)', '  (generator "rabbit_body_gen")',
               '  (layer "F.Cu")', f'  (descr "{self.descr}")', f'  (attr {self.attr})',
               f'  (property "Reference" "REF**" (at 0 {_f(ref_y)} 0) (layer "F.SilkS") '
               f'(effects (font (size 1 1) (thickness 0.15))))',
               f'  (property "Value" "{self.name}" (at 0 {_f(val_y if val_y is not None else 0)} 0) (layer "F.Fab") '
               f'(effects (font (size 1 1) (thickness 0.15))))']
        out += self.items
        if self.model:
            p, z, rot = self.model
            out.append(f'  (model "{p}" (offset (xyz 0 0 {_f(z)})) (scale (xyz 1 1 1)) (rotate (xyz 0 0 {_f(rot)})))')
        out.append(")")
        (LIB / f"{self.name}.kicad_mod").write_text("\n".join(out) + "\n")


def drv8316():
    """TI RGF0040E, body 5 (x) x 7 (y). Pins 1-12 left (top to bottom), 13-20 bottom, 21-32 right (bottom to top),
    33-40 top (right to left); pads 0.6 x 0.25, pad centres at x +-2.4 (4.8 c-c) and y +-3.4 (6.8 c-c); EP 3.7 x 5.7 = pin 41."""
    f = FP("TI_RGF0040E_VQFN-40_5x7mm_P0.5mm_EP3.7x5.7mm", "TI DRV8316 RGF0040E VQFN-40 5x7 mm, 0.5 mm pitch, SLVSF16B p.93")
    for i in range(12):
        f.smd(str(1 + i), -2.4, -2.75 + 0.5 * i, 0.6, 0.25)
        f.smd(str(21 + i), 2.4, 2.75 - 0.5 * i, 0.6, 0.25)
    for i in range(8):
        f.smd(str(13 + i), -1.75 + 0.5 * i, 3.4, 0.25, 0.6)
        f.smd(str(33 + i), 1.75 - 0.5 * i, -3.4, 0.25, 0.6)
    f.smd("41", 0, 0, 3.7, 5.7, "rect", paste=False)
    for x in (-0.9, 0.9):
        for y in (-1.95, -0.65, 0.65, 1.95):
            f.paste(x, y, 1.3, 1.0)
    for x in (-1.25, 0.0, 1.25):
        for y in (-2.25, -1.125, 0.0, 1.125, 2.25):
            f.tht("41", x, y, 0.5, 0.3, layers='"*.Cu"')
    f.rect("F.Fab", -2.5, -3.5, 2.5, 3.5)
    f.rect("F.CrtYd", -2.95, -3.95, 2.95, 3.95, 0.05)
    f.pin1(-3.1, -3.6)
    f.set_model(M3D + "vqfn40_5x7.step")
    f.write(-4.4, 4.4)


def lm61495():
    """TI RPH0016B (VQFN-HR 4.5 x 3.5). Left: 1 PGND2, 2 VIN2, 3 RBOOT, 4 CBOOT, 5 BIAS, 6 VCC; bottom: 7 FB, 8 AGND,
    9 RT; right (bottom to top): 10 RESET, 11 SPSP, 12 SYNC/MODE, 13 EN, 14 VIN1, 15 PGND1; centre: 16 SW (SNVSBZ4A p.3-4).
    Geometry from the land pattern p.59 (drawing y up -> KiCad y down)."""
    f = FP("TI_RPH0016B_VQFN-HR-16_3.5x4.5mm", "TI LM61495 RPH0016B VQFN-HR-16, SNVSBZ4A p.59")
    def r(x0, y0, x1, y1):            # drawing coordinates (y up) -> KiCad rect
        return (x0, -y1, x1, -y0)
    for s, n_top, n_bot in ((-1, "1", "6"), (1, "15", "10")):
        lo, hi = sorted((s * 0.803, s * 1.954)); nlo, nhi = sorted((s * 0.803, s * 1.601))
        f.poly_pad(n_top, [r(lo, 1.353, hi, 2.104), r(nlo, 2.104, nhi, 2.451)])
        blo, bhi = sorted((s * 0.85, s * 1.954)); nblo, nbhi = sorted((s * 0.85, s * 1.601))
        f.poly_pad(n_bot, [r(blo, -2.098, bhi, -1.902), r(nblo, -2.451, nbhi, -2.098)])
    f.smd("2", -1.4165, -0.552, 1.075, 0.4)
    f.smd("14", 1.4165, -0.552, 1.075, 0.4)
    for n_l, n_r, y in (("3", "13", -0.525), ("4", "12", -1.025), ("5", "11", -1.525)):
        f.smd(n_l, -1.5405, -y, 0.827, 0.25)
        f.smd(n_r, 1.5405, -y, 0.827, 0.25)
    f.smd("16", 0, -0.963, 0.35, 2.977)
    f.smd("7", -0.5, 2.1155, 0.25, 0.671)
    f.smd("8", 0, 2.0405, 0.25, 0.821)
    f.smd("9", 0.5, 2.1155, 0.25, 0.671)
    f.rect("F.Fab", -1.75, -2.25, 1.75, 2.25)
    f.rect("F.CrtYd", -2.2, -2.7, 2.2, 2.7, 0.05)
    f.pin1(-2.35, -2.75)
    f.set_model(M3D + "vqfn16_3.5x4.5.step")
    f.write(-3.5, 3.5)


def lm74800():
    """TI DRR0012E WSON-12 3 x 3: pads 0.62 x 0.25 at x +-1.39 (2.78 c-c), pins 1-6 left top to bottom, 7-12 right bottom to top;
    EP 1.3 x 2.5 (RTN, must float: SNOSDD8 p.3)."""
    f = FP("TI_DRR0012E_WSON-12_3x3mm_P0.5mm_EP1.3x2.5mm", "TI LM74800 DRR0012E WSON-12, SNOSDD8 p.41")
    for i in range(6):
        f.smd(str(1 + i), -1.39, -1.25 + 0.5 * i, 0.62, 0.25)
        f.smd(str(7 + i), 1.39, 1.25 - 0.5 * i, 0.62, 0.25)
    f.smd("13", 0, 0, 1.3, 2.5, "rect", paste=False)
    for y in (-0.6, 0.6):
        f.paste(0, y, 1.0, 0.95)
    f.rect("F.Fab", -1.5, -1.5, 1.5, 1.5)
    f.rect("F.CrtYd", -1.95, -1.75, 1.95, 1.75, 0.05)
    f.pin1(-1.95, -1.9)
    f.set_model(M3D + "wson12_3x3.step")
    f.write(-2.6, 2.6)


def fuse_2410():
    f = FP("Fuse_Littelfuse_NANO2_451_2410", "Littelfuse NANO2 451 series 2410 fuse, recommended pads 1.96 x 3.15, gap 2.95")
    for num, x in (("1", -2.455), ("2", 2.455)):
        f.smd(num, x, 0, 1.96, 3.15, "rect")
    f.rect("F.Fab", -3.05, -1.25, 3.05, 1.25)
    f.rect("F.SilkS", -1.3, -1.7, 1.3, 1.7)
    f.rect("F.CrtYd", -3.7, -1.85, 3.7, 1.85, 0.05)
    f.set_model(M3D + "fuse_2410.step")
    f.write(-2.6, 2.6)


def shunt_2512():
    f = FP("R_Shunt_2512_Kelvin", "2512 current-sense resistor with split Kelvin pads: 1/2 current, 3/4 sense")
    for s, ci, si in ((-1, "1", "3"), (1, "2", "4")):
        f.smd(ci, s * 3.05, -0.45, 1.9, 2.5, "rect")
        f.smd(si, s * 3.05, 1.55, 1.9, 0.7, "rect")
    f.rect("F.Fab", -3.15, -1.6, 3.15, 1.6)
    f.rect("F.CrtYd", -4.25, -2.2, 4.25, 2.2)
    f.set_model("${KICAD10_3DMODEL_DIR}/Resistor_SMD.3dshapes/R_2512_6332Metric.step")
    f.write(-2.6, 2.6)


def net_tie():
    """Star point GND_MOT -> GND: 3.5 mm copper bridge."""
    f = FP("NetTie_3.5mm", "Net tie, 2 pads, 3.5 mm wide copper bridge for the motor return star point")
    f.items.append('  (net_tie_pad_groups "1, 2")')
    f.smd("1", -2.0, 0, 3.5, 3.5, "circle", paste=False)
    f.smd("2", 2.0, 0, 3.5, 3.5, "circle", paste=False)
    f.items.append('  (fp_poly (pts (xy -2 -1.75) (xy 2 -1.75) (xy 2 1.75) (xy -2 1.75)) (stroke (width 0) (type solid)) '
                   '(fill yes) (layer "F.Cu"))')
    f.rect("F.CrtYd", -3.75, -1.85, 3.75, 1.85, 0.05)
    f.write(-2.8, 2.8)


def rpi4():
    f = FP("RaspberryPi4_Standoffs", "Raspberry Pi 4 on 4x M2.5 x 6 mm standoffs, component side up; origin = board centre")
    f.attr = "board_only exclude_from_pos_files exclude_from_bom"
    for x, y in ((3.5, 3.5), (61.5, 3.5), (3.5, 52.5), (61.5, 52.5)):
        f.npth(x - 42.5, 28.0 - y, 2.7)
        f.circle("F.Fab", x - 42.5, 28.0 - y, 3.0, 0.1)
    f.rect("F.Fab", -42.5, -28.0, 42.5, 28.0)
    f.rect("F.SilkS", -42.0, -27.2, 42.0, 27.2)
    f.rect("F.CrtYd", -42.75, -28.25, 45.25, 28.25)
    f.rect("F.Fab", 42.5 - 19.0, 28.0 - 53.75, 45.0, 28.0 - 37.75)
    f.rect("F.Fab", 42.5 - 17.0, 28.0 - 33.5, 44.5, 28.0 - 2.5)
    f.text("F.SilkS", "RASPBERRY PI 4", -8, 0, 2.5)
    f.text("F.SilkS", "USB / ETH", 34, 0, 1.2)
    f.set_model(M3D + "rpi4.step", z=6.0)
    f.write(-29.5, 29.5)


def main():
    if LIB.exists():
        shutil.rmtree(LIB)
    LIB.mkdir(parents=True)
    for fn in (drv8316, lm61495, lm74800, fuse_2410, shunt_2512, net_tie, rpi4):
        fn()
    print("footprints in", LIB)


if __name__ == "__main__":
    main()

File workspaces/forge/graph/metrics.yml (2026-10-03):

nodes:
  battery_voltage:
    label: Battery voltage
    group: power
    unit: V
    description: Pack voltage at the INA4235; it sags with total current and falls slowly with charge.
    source:
      table: power
      expr: "battery_voltage"
    hz: 50
    floor: 0.005
    slabs: [battery_sag, battery_resistance, run_summary, brownout_and_gaps]
  battery_current:
    label: Battery current
    group: power
    unit: A
    description: Total current out of the pack, motors through the 12 V buck plus Jetson, camera and servos.
    source:
      table: power
      expr: "battery_current"
    hz: 50
    floor: 0.01
    slabs: [battery_sag, power_budget]
  battery_power:
    label: Battery power
    group: power
    unit: W
    description: Total power drawn from the pack.
    source:
      table: power
      expr: "battery_power"
    hz: 50
    floor: 0.1
    slabs: [power_budget, power_rails, battery_sag]
  battery_charge:
    label: Charge estimate
    group: power
    unit: "%"
    description: State of charge from the voltage curve; it reads low under load.
    source:
      table: power
      expr: "battery_charge_pct"
    hz: 50
    floor: 0.5
    slabs: [battery_sag, run_summary]
  servo_power:
    label: Servo rail power
    group: power
    unit: W
    description: Power on the 6 V steering servo rail.
    source:
      table: power
      expr: "rail_6v_power"
    hz: 50
    floor: 0.05
    slabs: [power_rails, power_budget]
  supply_voltage:
    label: 12 V motor supply
    group: power
    unit: V
    description: Buck converter output feeding the motor controller, not the battery.
    source:
      table: roboclaw
      expr: "supply_voltage"
    hz: 50
    floor: 0.1
    slabs: [battery_sag]
  motor_current:
    label: Motor current
    group: motors
    unit: A
    description: Left plus right absolute motor current at 12 V.
    source:
      table: roboclaw
      expr: "abs(left_current) + abs(right_current)"
    hz: 50
    floor: 0.01
    slabs:
      [
        drive_tracking,
        stall_events,
        motor_power_by_side,
        turn_current,
        battery_sag,
      ]
  motor_current_left:
    label: Left motor current
    group: motors
    unit: A
    description: Absolute current of the left motor (M1).
    source:
      table: roboclaw
      expr: "abs(left_current)"
    hz: 50
    floor: 0.01
    slabs: [motor_power_by_side, stall_events]
  motor_current_right:
    label: Right motor current
    group: motors
    unit: A
    description: Absolute current of the right motor (M2).
    source:
      table: roboclaw
      expr: "abs(right_current)"
    hz: 50
    floor: 0.01
    slabs: [motor_power_by_side, stall_events]
  motor_power:
    label: Motor power
    group: motors
    unit: W
    description: Electrical power into both motors, 12 V supply times summed motor current.
    source:
      {
        table: roboclaw,
        expr: supply_voltage * (abs(left_current) + abs(right_current)),
      }
    hz: 50
    floor: 0.1
    slabs: [motor_power_by_side, power_budget]
  drive_command:
    label: Drive command
    group: motion
    unit: duty 0..1
    description: Mean absolute duty commanded to the two motors, from the gamepad or navigation.
    source:
      { table: roboclaw, expr: (abs(left_command) + abs(right_command)) / 2 }
    hz: 50
    floor: 0.01
    slabs: [drive_tracking, mission_timeline]
  motor_pwm:
    label: Applied PWM
    group: motion
    unit: duty 0..1
    description: Mean absolute PWM duty the controller actually applied after ramping.
    source:
      table: roboclaw
      expr: "(abs(left_pwm) + abs(right_pwm)) / 2"
    hz: 50
    floor: 0.01
    slabs: [stall_events, motor_power_by_side]
  nav_speed_command:
    label: Navigation speed command
    group: navigation
    unit: duty 0..1
    description: Absolute speed commanded by autonomous navigation.
    source:
      table: nav_state
      expr: "abs(speed)"
    hz: 10
    floor: 0.01
    slabs: [mission_timeline, drive_tracking]
  ground_speed:
    label: Ground speed
    group: motion
    unit: m/s
    description: Speed from the ZED pose velocity; the wheel encoders are not connected.
    source:
      table: pose
      expr: "sqrt(vx * vx + vy * vy + vz * vz)"
    hz: 30
    floor: 0.005
    slabs: [drive_tracking, trajectory, stall_events]
  steering_angle:
    label: Steering lock
    group: motion
    unit: -1..1
    description: Absolute applied steering angle, 1 is full lock.
    source:
      table: steering
      expr: "abs(angle)"
    hz: 20
    floor: 0.01
    slabs: [steering_response, turn_current]
  yaw_rate:
    label: Yaw rate
    group: motion
    unit: deg/s
    description: Absolute turn rate from the IMU gyro.
    source:
      table: imu
      expr: "abs(gyro_y)"
    hz: 100
    floor: 0.2
    slabs: [steering_response]
  imu_vibration:
    label: IMU vibration
    group: motion
    unit: g
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

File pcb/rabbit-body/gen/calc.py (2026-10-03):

"""Rev B design numbers: dividers, thresholds, timings, copper widths, thermal estimates.

Run with any Python 3: python3 gen/calc.py. The report docs/reports/2026-10-03-body-pcb-rev-b.md quotes these.
Datasheet references are in the report (page numbers); the constants here are copied from them.
"""
import math

E96 = [1.00, 1.02, 1.05, 1.07, 1.10, 1.13, 1.15, 1.18, 1.21, 1.24, 1.27, 1.30, 1.33, 1.37, 1.40, 1.43, 1.47, 1.50,
       1.54, 1.58, 1.62, 1.65, 1.69, 1.74, 1.78, 1.82, 1.87, 1.91, 1.96, 2.00, 2.05, 2.10, 2.15, 2.21, 2.26, 2.32,
       2.37, 2.43, 2.49, 2.55, 2.61, 2.67, 2.74, 2.80, 2.87, 2.94, 3.01, 3.09, 3.16, 3.24, 3.32, 3.40, 3.48, 3.57,
       3.65, 3.74, 3.83, 3.92, 4.02, 4.12, 4.22, 4.32, 4.42, 4.53, 4.64, 4.75, 4.87, 4.99, 5.11, 5.23, 5.36, 5.49,
       5.62, 5.76, 5.90, 6.04, 6.19, 6.34, 6.49, 6.65, 6.81, 6.98, 7.15, 7.32, 7.50, 7.68, 7.87, 8.06, 8.25, 8.45,
       8.66, 8.87, 9.09, 9.31, 9.53, 9.76]


def e96(x):
    d = 10 ** math.floor(math.log10(x))
    return min((v * d for v in E96 + [10.0]), key=lambda v: abs(v - x))


def par(*r):
    return 1 / sum(1 / x for x in r)


def ipc_current(width_mm, oz=1.0, rise=20.0, k=0.024):
    """IPC-2152 conservative fit (the IPC-2221 internal-layer curve, used for every layer)."""
    area_mil2 = width_mm / 0.0254 * oz * 1.378
    return k * rise ** 0.44 * area_mil2 ** 0.725


def ipc_width(current, oz=1.0, rise=20.0, k=0.024):
    area = (current / (k * rise ** 0.44)) ** (1 / 0.725)
    return area / (oz * 1.378) * 0.0254


def main():
    out = []
    p = out.append

    # LM74800 (SNOSDD8): EN/UVLO rising 1.231 V, falling 1.132 V (p.5); OV rising 1.231, falling 1.13 (p.5)
    ov_top, ov_bot = 150e3, 10e3
    p(f"LM74800 OV cut-off: {1.231 * (1 + ov_top / ov_bot):.1f} V rising, {1.13 * (1 + ov_top / ov_bot):.1f} V falling")
    # inrush: C_dVdT = I_HGATE x C_OUT / I_INRUSH (p.16), I_HGATE 55 uA
    c_out, c_dvdt = 3 * 220e-6 + 12 * 10e-6 + 10 * 22e-6, 47e-9
    slew = 55e-6 / c_dvdt
    p(f"VBUS capacitance ~{c_out * 1e6:.0f} uF; HGATE slew {slew:.0f} V/s; inrush {c_out * slew:.2f} A; "
      f"ramp to 16.8 V in {16.8 / slew * 1e3:.0f} ms (DRV8316 VM limit 4 V/us, SLVSF16B p.6)")
    # soft latch: EN = 220k to GND; button path PNP collector -> 47k; hold path VBUS -> 8.2 V zener -> 47k
    r_pd, r_on, r_hold, vz = 220e3, 47e3, 47e3, 8.2
    en_hold = (16.8 - vz) * r_pd / (r_pd + r_hold)
    v_release = vz + 1.132 * (r_pd + r_hold) / r_pd
    p(f"latch: EN held at {en_hold:.1f} V at 16.8 V; releases when VBUS < {v_release:.1f} V")
    en_btn = (16.8 - 0.2) * par(r_pd, r_hold) / (r_on + par(r_pd, r_hold))
    p(f"latch: button press puts EN at {en_btn:.1f} V with VBUS = 0 (threshold 1.231 V)")
    tau_off = 1e6 * 1e-6
    t_hold = tau_off * math.log((3.3 - 0.3) / 1.0)
    p(f"OFF FET gate held > 1.0 V for {t_hold:.2f} s after the Pi dies (1 uF, 1 MOhm, BAT54 drop 0.3 V)")
    c_bus = c_out + 2 * 470e-6
    p(f"VBUS fall 16.8 -> {v_release:.1f} V at 50 mA (Pi halted): {c_bus * (16.8 - v_release) / 0.05 * 1e3:.0f} ms")

    # LM61495 (SNVSBZ4A): VFB 1.0 V (p.14 eq.1), EN rising 1.263 V (p.6)
    for name, rbot in (("5V body", 24e3), ("6V servo", 20e3)):
        p(f"LM61495 {name}: RFBT 100k, RFBB {rbot / 1e3:.1f}k -> {1.0 * (1 + 100e3 / rbot):.3f} V")
    p(f"LM61495 EN divider 100k/22k: starts at {1.263 * 122 / 22:.1f} V")

    # TPS16630 (SLVSET9G): UVLO/OVP rising 1.2 V (p.8), I_OL = 18 / R_ILIM[kOhm] (p.20 eq.6), t_dVdT eq.2 (p.17)
    p(f"TPS16630 UVLO 68k/10k: {1.2 * (1 + 68 / 10):.2f} V; OVP 150k/10k: {1.2 * (1 + 15):.1f} V")
    for name, rilim, cdvdt in (("Jetson", 3.9, 47e-9),):
        p(f"TPS16630 {name}: R_ILIM {rilim}k -> {18 / rilim:.2f} A, t_dVdT at 16.8 V = {20.8e3 * 16.8 * cdvdt * 1e3:.1f} ms")

    # brake chopper: LM393 on MOT_BUS, TL431 2.495 V, output pull-up to a 12 V zener-clamped gate
    vref, r2, vg = 2.495, 10e3, 12.0
    best = None
    for r1 in (e96(x * 1e3) for x in range(55, 70)):
        for rh in (1.0e6, 1.2e6, 1.5e6, 2.0e6):
            on = vref * (r1 + par(r2, rh)) / par(r2, rh)
            g = 1 / r1 + 1 / r2 + 1 / rh
            off = r1 * (vref * g - vg / rh)
            err = abs(on - 17.6) + abs(off - 17.2)
            if best is None or err < best[0]:
                best = (err, r1, rh, on, off)
    _, r1, rh, on, off = best
    p(f"brake: R1 {r1 / 1e3:.1f}k, R2 10k, Rh {rh / 1e3:.0f}k -> on {on:.2f} V, off {off:.2f} V")
    rb = 39.0 / 4
    p(f"brake resistor 4 x 39 Ohm = {rb:.2f} Ohm: {17.6 / rb:.2f} A, {17.6 ** 2 / rb:.1f} W while on; "
      f"14 J (stop from 2.5 m/s) in {14 / (17.6 ** 2 / rb):.2f} s, {14 / 4:.1f} J per 2512")

    # E-stop timing: 100k x 2.2 uF into a Schmitt NAND (SN74LVC1G132 at 3 V: VT- 0.84-1.14 V, VT+ 1.5-1.87 V, p.6)
    lo, hi = (100e3 * 2.2e-6 * math.log(3.3 / v) * 1e3 for v in (1.14, 0.84))
    p(f"E-stop -> DRVOFF delay {lo:.0f}-{hi:.0f} ms (TIM BKIN brakes at once)")

    # copper (1 oz outer, 0.5 oz inner), 20 C rise
    for net, amps in (("battery/VBUS", 14), ("motor branch", 8), ("Jetson", 4.5), ("5 V Pi", 4), ("6 V servo", 6),
                      ("phase", 8), ("VBUS spine", 10)):
        p(f"IPC-2152 {net} {amps} A: {ipc_width(amps):.1f} mm on one 1 oz layer, {ipc_width(amps / 2):.1f} mm on each of two")

    # as built (routing.py): narrowest section of each power path, layers, required current
    for name, width, layers, need in (("BAT_IN / BAT_F / SW_MID pours", 9.2, 2, 14), ("VBUS_RAW pour", 6.4, 2, 14),
                                      ("VBUS spine under the Pi", 7.5, 2, 10), ("MOT_F", 6.1, 2, 8),
                                      ("MOT_BUS corridor", 2.7, 2, 4), ("MOT_BUS bar (F only, DRV L)", 5.0, 1, 4),
                                      ("phase track F + B", 1.5, 2, 3), ("+5 V to the Pi header", 2.0, 1, 2.5),
                                      ("6 V to the servo shunt", 3.0, 1, 3), ("SERVO_6V pour (B)", 6.0, 1, 6),
                                      ("JET_OUT pour (F)", 3.0, 1, 3.5), ("JET_PWR pour (F + B)", 4.0, 2, 4.5),
                                      ("GND_MOT island (In1 0.5 oz alone, F.Cu fill not counted)", 20.0, 1, 6)):
        cap = ipc_current(width, 0.5 if name.startswith("GND_MOT") else 1.0) * layers
        p(f"as built {name}: {width} mm x {layers} -> {cap:.1f} A at +20 C (needs {need} A)")
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

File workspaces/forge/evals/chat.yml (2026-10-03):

- id: battery_average
  anchor: |
    WITH (SELECT run_id FROM runs WHERE stopped_at IS NOT NULL ORDER BY duration_s DESC LIMIT 1) AS r
    SELECT r AS run, avg(battery_voltage) AS v,
      concat('(', replace(toDecimalString(floor(v, 1), 1), '.', '[.,]'), '|', replace(toDecimalString(ceil(v, 1), 1), '.', '[.,]'), ')') AS v_re
    FROM power WHERE run_id = r
  question: What was the average battery voltage in run {run}?
  all: [run_slab]
  facts: ["{v_re}"]
- id: english_only
  anchor: |
    WITH (SELECT run_id FROM runs WHERE stopped_at IS NOT NULL ORDER BY duration_s DESC LIMIT 1) AS r
    SELECT r AS run, avg(battery_voltage) AS v,
      concat('(', replace(toDecimalString(floor(v, 1), 1), '.', '[.,]'), '|', replace(toDecimalString(ceil(v, 1), 1), '.', '[.,]'), ')') AS v_re
    FROM power WHERE run_id = r
  question: ¿Cuál fue el voltaje medio de la batería en la carrera {run}?
  all: [run_slab]
  facts: ["{v_re}", "battery", "voltage"]
- id: chart_voltage
  anchor: SELECT run_id FROM runs WHERE stopped_at IS NOT NULL ORDER BY duration_s DESC LIMIT 1
  question: Chart the battery voltage for run {run_id}
  all: [chart]
- id: power_budget
  anchor: SELECT run_id FROM runs WHERE stopped_at IS NOT NULL ORDER BY duration_s DESC LIMIT 1
  question: What uses the most power in run {run_id}?
  all: ["run_slab:power_budget"]
  facts: ["jetson"]
- id: battery_clipped
  anchor: SELECT run_id FROM power WHERE battery_clipped GROUP BY run_id ORDER BY max(battery_current) DESC LIMIT 1
  question: What was the highest battery current in run {run_id}, and is that the real peak?
  facts: ["clip|saturat|ceiling|lower bound|range"]
- id: compare_runs
  anchor: |
    SELECT groupArray(run_id)[1] AS a, groupArray(run_id)[2] AS b
    FROM (SELECT run_id FROM runs WHERE stopped_at IS NOT NULL ORDER BY duration_s DESC LIMIT 2)
  question: Compare runs {a} and {b}
  all: ["run_slab:run_compare"]
- id: missions
  anchor: |
    SELECT run_id, count() AS missions FROM nav_events
    WHERE event IN ('goal', 'mission') GROUP BY run_id ORDER BY missions DESC LIMIT 1
  question: Did the robot complete its missions in run {run_id}?
  all: ["run_slab:nav_missions"]
  facts: ["arriv|complet|reach|fail|cancel"]
- id: tracking
  anchor: |
    SELECT run_id FROM zed_health GROUP BY run_id
    ORDER BY countIf(pose_state != 'OK') / count() DESC LIMIT 1
  question: Did the camera lose tracking in run {run_id}?
  any: ["run_slab:tracking_quality", "detect_anomalies:zed_fps"]
- id: vibration
  anchor: SELECT run_id FROM runs WHERE stopped_at IS NOT NULL ORDER BY duration_s DESC LIMIT 1
  question: Were there any bumps or vibration in run {run_id}?
  any: ["run_slab:imu_shocks", "detect_anomalies:imu_vibration"]
- id: wifi
  anchor: SELECT run_id FROM wifi ORDER BY gateway_rtt_ms DESC NULLS LAST LIMIT 1
  question: Was there high ping or packet loss on Wi-Fi in run {run_id}?
  all: ["run_slab:wifi_health"]
- id: encoders
  anchor: SELECT run_id FROM runs WHERE stopped_at IS NOT NULL ORDER BY duration_s DESC LIMIT 1
  question: How far did the wheel encoders say the robot drove in run {run_id}?
  facts:
    [
      "encoder",
      "not connected|n.t connected|disconnected|always (0|zero)|no (wheel-)?encoder",
    ]
- id: stall
  anchor: &peak |
    SELECT run_id,
      concat(formatDateTime(ts, '%H:%i', 'UTC'), '|', replaceRegexpOne(formatDateTime(ts, '%H:%i', 'Australia/Sydney'), '^0', '0?')) AS at_re,
      formatDateTime(ts, '%H:%i', 'UTC') AS at_utc,
      formatDateTime(ts - INTERVAL 2 MINUTE, '%Y-%m-%d %H:%i:%S', 'UTC') AS window_from,
      formatDateTime(ts + INTERVAL 2 MINUTE, '%Y-%m-%d %H:%i:%S', 'UTC') AS window_to
    FROM roboclaw
    WHERE greatest(abs(left_pwm), abs(right_pwm)) > 0.05
    ORDER BY abs(left_current) + abs(right_current) DESC LIMIT 1
  question: Did the motors stall or spike in run {run_id}?
  all: ["run_slab:stall_events"]
  facts: ["{at_re}"]
- id: motor_anomaly_window
  anchor: *peak
  question: Was anything unusual with the motor current in run {run_id} between {window_from} and {window_to} UTC?
  all: ["detect_anomalies:motor_current"]
  facts: ["{at_re}"]
- id: multi_metric_anomaly
  anchor: *peak
  question: Did battery voltage and motor current misbehave together between {window_from} and {window_to} UTC in run {run_id}?
  all: ["detect_anomalies:battery_voltage", "detect_anomalies:motor_current"]
  facts: ["{at_re}"]
- id: spike_cause
  anchor: *peak
  question: Why did the motor current spike around {at_utc} UTC in run {run_id}?
  any:
    [
      "investigate:motor_current",
      "detect_anomalies:motor_current",
      "run_slab:stall_events",
    ]
  facts: ["command|throttle|drive|pwm|stall|inrush|start|obstacle|wall"]
- id: data_gaps
  anchor: &gap |
    SELECT run_id,
      concat(formatDateTime(prev, '%H:%i', 'UTC'), '|', replaceRegexpOne(formatDateTime(prev, '%H:%i', 'Australia/Sydney'), '^0', '0?')) AS at_re,
      formatDateTime(prev, '%H:%i', 'UTC') AS at_utc
    FROM (
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

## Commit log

2025-05-25 add python
    [rabbit_1.kicad_pcb, rabbit_1.kicad_sch]
2025-08-18 Track large binaries with Git LFS
2026-10-01 Add chassis model, rabbit PCB, perception node; update roboclaw and steering
    [rabbit-board.kicad_pcb, rabbit-board.kicad_sch]
2026-10-01 feat: ZED SDK perception, navigation, exploration and HUD rework
    - replace custom perception and nvblox with ZED SDK 5.5 tracking, spatial mapping and continuous floor estimation
    - add nav node with missions, swept-footprint collision guard and Hybrid A* planner, plus frontier exploration
    - rewrite RoboClaw and steering drivers with kill switches and command arbitration
    - rebuild the web HUD: room mesh, Forge chat with widgets, keyboard driving, telemetry charts
    - fix ZED event-loop stalls (live mesh filter, adaptive map interval) and telemetry blocking
    [compose.yaml, steering.py]
2026-10-01 feat: Forge robot analytics with ClickHouse, slabs, MCP and chat agent
    [motor_power_by_side.yml]
2026-10-01 fix: keep nav safety trips armed and path following on track
    - trip() keyed off the fault string, so a goal rejected mid-mission disabled every stall, collision, timeout and deadman trip; gate on mode instead
    - a manoeuvre-failed trip inside flip_direction was followed by a non-zero drive command
    - reverse pure pursuit looked up steer in the wrong side's curvature table
    - re-anchoring dropped remembered obstacles and left queued path steps in the old frame
    - a cusp or path end passed outside its tolerance made the robot drive away; treat a passed end within the lookahead as reached
2026-10-01 fix: explore planning races and mission ownership
    - snapshot map chunks and pose before planning in the worker thread
    - count blocked retries per frontier by radius, not exact centroid
    - stop exploring when nav's mission is cancelled from outside (manual override) instead of driving the next frontier
    - cancel the running nav mission when exploration is cancelled, restarted or shut down
2026-10-01 fix: serialize ZED tracking restart with the map worker and sensor polling
2026-10-01 fix: drop NATS healthcheck that needs a CLI missing from the image
    [compose.yaml]
2026-10-01 fix: publish pose before obstacles and tolerate shutdown before sensors start
2026-10-01 fix: track explore missions by id and time out blocked reverse driving
2026-10-01 feat: run the writer and chat server as Compose services
    The writer and chat API now run in Docker next to ClickHouse with
    restart: unless-stopped, so recording no longer stops with the session
    that started it. The writer starts without the robot and keeps
    reconnecting to NATS, caps buffered rows across all tables, retries a
    missing table instead of bisecting it, and logs insert failures.
2026-10-01 fix: check missions along the planned path and confirm nav accepts them
    Goto legs are measured from where earlier steps leave the robot, camera
    and obstacle readings must be fresh, and the obstacle check applies to
    the first leg that moves. run_mission sends its own id and waits for
    nav_state to adopt it, reporting a fresh rejection. Approvals no longer
    grow without bound, and logs keep a deduplication window.
2026-10-01 fix: abort abandoned chats, gate APPLY functions and bound caches
    A client disconnect aborts the agent run and stream errors no longer
    escape, client system messages are refused, functions named in APPLY
    go through the allowlist, timeline bins are whole milliseconds, and the
    forecast and map chunk caches stop growing.
2026-10-01 perf: batch map chunks into grouped draw calls and drop repaint-heavy HUD effects
    Merge spatial-map chunks into 16-chunk meshes rebuilt under a per-frame
    budget, so draw calls no longer grow one per chunk. Move the STOP pulse
    glow to a compositor-only opacity animation, replace the modal backdrop
    blur with a darker scrim, and flicker a HUD value at most once a second.
2026-10-01 fix: detect a dead NATS link, retry the map snapshot and mark stale HUD data
    Ping every 3 s and report a stale connection as reconnecting, wait for
    the first connection instead of failing, retry the map snapshot until a
    responder answers, dim values of panels whose source is lost, show NO
    SIGNAL on a frozen camera feed and decode the preview at display size.
    VITE_NATS_URL overrides the NATS server for local testing.
2026-10-01 fix: wait for NATS at node startup and skip corrupted ZED frames
2026-10-01 fix: track paths by the rear axle and reject isolated depth points in obstacle scans
    - pure pursuit follows rear-axle points derived from the camera path, so reverse segments converge instead of drifting
    - path ends and gear switches use 5 cm tolerances, relying on the passed-end check for overshoot
    - scan bins and nearest/ahead use the 4th nearest point and drop points inside the depth blind zone
2026-10-01 feat: turn the ground ring into a compass and show the live steering corridor
    The ring under the robot is now a world-aligned compass (N/E/S/W, 5° ticks)
    with a heading marker driven by derived.heading, so it always agrees with
    the top compass strip. The live steering angle is drawn as the swept
    footprint corridor of the rear axle (curvature tables, footprint and
    offsets from lib/geometry.py and lib/safety.py), forward or backward by
    the sign of the motor command, dimmed while a mission is active, and
    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
2026-10-01 fix: persist the room mesh across restarts and keep map coordinates valid far from the origin
    - map chunks carry a float origin, so vertices no longer overflow int16 beyond 32 m
    - the saved mesh reloads as a base layer once tracking relocalizes, and live chunks retire base chunks they cover
    - mapping waits for relocalization, the relocalization timeout counts only camera motion, and nothing is saved before relocalizing
    - poses with zero confidence are not published and a fresh tracking session starts at the origin
    - publishes during a NATS reconnect are dropped and counted instead of raising, and the server tolerates 10 s write stalls
2026-10-01 fix: measure obstacle height from a per-frame floor plane so the floor is not reported as a contact
2026-10-01 feat: add a live floor-plan minimap to the HUD
    RoomMap hands every decoded chunk (and tombstone) to a worker that
    rasterises it into 5 cm cells, floor below 4 cm and obstacles in the
    4-45 cm band the robot checks, keeping per-chunk contributions so updates
    and deletions touch only their cells. Changed 64x64 tiles come back as
    bitmaps and are blitted into one raster canvas.
    The MAP panel draws that raster with the robot footprint, live obstacle
    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
2026-10-01 fix: restart the camera process after a tracking failure and reconnect a silent jtop client
    - a pose/IMU tilt mismatch discards the failed session and restarts the process, which then relocalizes against the last saved map; the map is archived only when relocalization fails or the failure repeats within two minutes of start
    - re-enabling tracking in-process left the SDK in a broken state and produced poses tens of metres away
    - the telemetry node recreates its jtop client after 5 s without data
2026-10-01 docs: describe the camera process restart in the robot skills
2026-10-01 fix: keep the HUD proxy working across chat restarts and open the robot ClickHouse to the LAN
    - nginx resolves forge-chat through Docker DNS on every request instead of once at start
    - the Mac's Forge CLI and MCP read the robot's ClickHouse on port 18123
    - docs and skills describe the merged repo and the robot-hosted services
    [compose.yaml]
2026-10-01 feat: map reset action, faster deploys and a shareable tunnel
    - rabbit.map.reset archives the saved map and restarts the camera; the HUD map panel and the chat (with approval) can send it
    - the chat agent no longer appends a reminder after an approval response, which kept approved tools from running
    - one shared rabbit image for all nodes, Forge sources mounted into a deps-only image, small build contexts, and deploys that build only with --build
    - nginx proxies the NATS websocket, so the HUD works from any address, and a Cloudflare quick tunnel shares it
    [compose.yaml]
2026-10-01 feat: HUD panels as scrollable accordion columns
    - each side is a scrolling column where any number of panels stay open; panels no longer collapse automatically when space runs out
    - the move-up control and the animated layout engine are gone, the engine keeps only frame and tick listeners
    - nginx serves index.html with no-cache so a deploy shows up on reload
2026-10-01 perf: batch ClickHouse inserts every 10 s and run ClickHouse at low CPU priority on the robot
    - the writer flushed every table each second, about 14 inserts and new parts a second; now about 2.5, with inserts taking 3 s of CPU a minute instead of 20
    - forge-clickhouse gets cpu_shares 256 and one core so the camera wins under contention
    - the writer's rows/s report counts received messages, which stays steady with the longer flush
2026-10-02 perf: spread Jetson interrupts, keep PCIe out of power saving and version the boot tuning script
    - camera USB, RoboClaw UART and I2C interrupts move off CPU0, which sat at 100% while other cores idled at about 50%
    - PCIe ASPM runs in performance mode so the Wi-Fi card does not drop into low-power states
    - swappiness 10 keeps process memory out of swap
2026-10-02 docs: note that the Jetson runs headless
2026-10-02 fix: accept long chat histories and answer in Sydney time
    - nginx allowed 1 MB request bodies, and the chat sends the whole conversation with tool outputs, so long chats failed with 413
    - the agent receives the operator's current Australia/Sydney time and UTC offset with every question, converts the operator's times to UTC for tools and answers in local time
2026-10-03 feat(forge): Parquet + chDB store, observability tables and slabs, local times, chat fixes and evals
    Claude-Session: https://claude.ai/code/session_01BqVLDBXG9mdqYKRp3kWsAJ
    [chat.yml, metrics.yml]
2026-10-03 feat(hw): Rabbit 2.0 body PCB (KiCad, generated) and 3D-printed mounts
    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
    [ato_fuse_keystone_3557x2.step, bumper_front.3mf, bumper_front.step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]
2026-10-03 docs(blog): publish via GitHub Pages; DNS switch pending
    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
2026-10-03 docs: BLDC drive study for Rabbit 2.0
    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
2026-10-03 feat(hw): mounts for the 3-deck stack, PCB review fixes (TVS, ToF 3V3, motor star, ZED cutout)
    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
    [bumper_front.3mf, bumper_front.step, bumper_rear.3mf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]
2026-10-03 docs: body PCB review, mounts update, open issues
    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
2026-10-03 feat(body): Pi body nodes (lidar, ToF, safety, power), fake hardware, sim sensors, Forge tables, Pi deploy
    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
2026-10-03 docs(cad): lidar C1 yaw is 180 with the cable forward
    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
2026-10-03 docs: BLDC drive picks the JGB37-3625 10:1 with MT6701, AU sourcing, rev B requirements
    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
2026-10-03 docs: the drive motors are Pololu #4754 (37Dx70L, 64 CPR encoder, helical)
    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
2026-10-03 docs: drive study under the bolt-on rule: Pololu #4751 primary, Faulhaber/maxon need a new bracket
    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
2026-10-03 feat(hw): maxon ECX FLAT 22 + GPX 22 LN drive with a bearing-carried wheel bracket and Oldham coupling
    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
    [bracket.step, bracket_print.3mf, bracket_print.stl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]
2026-10-03 wip(hw): body PCB rev B in progress (BLDC drive, on-board power, factory assembly)
    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
    [fuse_2410.step, ina4235_dsbga16.step, pololu_big_pushbutton_hp.step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]
2026-10-03 chore(pcb): ignore KiCad lock files
    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
2026-10-04 wip(hw): body PCB rev B, state when paused
    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
    [rabbit-body.kicad_pcb]
2026-10-04 docs: note that PCB rev B is paused mid-routing
    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
2026-10-10 feat(blog): posts 190-193 on BLDC, agent-driven design, tooling and the body board
    Claude-Session: https://claude.ai/code/session_01DG9rbwZBLY4JaVomWyCqdL
2026-10-11 feat(blog): post 194 on routing the body board to zero with deeproute
    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
2026-10-19 feat(hw): body board rev C (8 layers, routed), ToF carrier, BLDC drop-in, datasheets
